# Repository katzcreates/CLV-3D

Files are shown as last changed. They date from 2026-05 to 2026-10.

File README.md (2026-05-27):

# CLV-3D: Closed Loop Ventilation Enclosure

A custom-built, sensor-driven ventilation enclosure designed for the safe operation of resin 3D printers in confined workshops.

## Overview

The CLV-3D is a multifunctional enclosure that addresses fume management and particulate filtration without requiring external exhaust. It features a high-volume recirculating airflow loop, real-time air quality monitoring, and autonomous fan control.

### Key Features

- **Recirculating Airflow**: Multi-pass filtration using G4 pre-filters and high-capacity carbon filters.
- **Distributed Sensor Network**: 4-node ESP-NOW system monitoring Internal, External, Plenum, and Filter environments.
- **Autonomous Control**: Fan speed scales automatically based on VOC (IAQ) and Particulate Matter (PM2.5 and PM10) levels.
- **Smart Idle & Self-Healing**: Adaptive power management and unified baseline calibration to prevent sensor drift.
- **Integrated Display**: Real-time dashboard showing system health and telemetry.

---

## Documentation

For detailed information on how to build, program, and maintain the CLV-3D, please refer to the following chapters:

- **[Electronics & Control Logic](docs/electronics.md)**: System architecture, wiring, and autonomous fan logic.
- **[Cabinetry & Assembly](docs/assembly.md)**: IKEA parts list, panel ordering, and physical construction.
- **[Firmware Setup & Calibration](docs/firmware.md)**: Library requirements, MAC addresses, and sensor calibration.
- **[Maintenance & Reliability](docs/maintenance.md)**: Filter lifespan, power management, and long-term stability.

*Documentation for Wireless Firmware coming soon.*

---

## System Architecture

The system consists of four wireless nodes communicating via ESP-NOW:

1. **Node 1 (Hub)**: Main display and user interface.
2. **Node 2 (Sensor Stack)**: Main control logic, fan driver, and internal sensors.
3. **Node 3 (Filter Monitor)**: Monitors pressure after the G4 filters to detect clogging.
4. **Node 4 (External Monitor)**: Reference node for room-air quality.

The as built system also features the following ventilation hardware:

- **Fan**: [Rhino Ultra Fan (150mm / 6" Non-Silenced)](https://rhinofilter.com/products/rhino-ultra-non-silenced-fan/)
- **Filter**: [AC Infinity 6" Carbon Filter](https://acinfinity.com/duct-carbon-filter-6-with-australian-charcoal/) (Intake)
- **Pre-filtration**: 2x [G4 Pleated Panel Filter (24"x12"x1" / EU4)](https://filtersdirect.uk/product/g4-pleated-panel-filter-1-22mm-depth-eu4/)

Other fans and filters can be used but adaptations to the design might be necessary to accomodate them. 

---

## Project Structure

- `firmware/`: Production firmware for all four nodes.
- `docs/`: Detailed technical documentation and assembly guides.
- `PressureCalibration/`: Utility script for sensor and pressure calibration.
- `3D Model References/`: Contains the master STEP assembly model (`CLV-3D Enclosure.step`) for the full enclosure.
- `3D Printing Files/`: Scaled STL files for all custom housings.
- `Cut Enclosure Pieces/`: DXF files for laser-cut panels.

---

## License & Credits

Designed by Katz Creates. This project is licensed under the **Creative Commons Attribution-NonCommercial-ShareAlike 4.0 International (CC BY-NC-SA 4.0)**.

See the [LICENSE](LICENSE) file for the full legal text.

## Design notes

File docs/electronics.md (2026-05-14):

# Electronics Design & Control Logic

The CLV-3D system follows a distributed design using ESP-NOW for wireless communication between a main display hub, a centralized sensor stack, and dedicated environmental monitors.

## System Architecture

```mermaid
graph TD
    subgraph "Node 1 - Hub (UM Feather S2)"
        N1[Feather S2] --- T["2.4 inch TFT FeatherWing"]
    end

    subgraph "Node 2 - Main Sensor Stack (QTPY S3)"
        N2[QTPY S3] --- S1[BME680 - Internal]
        N2[QTPY S3] --- S2[BME680 - Plenum]
        N2 --- PM[PMSA0031 - PM Sensor]
        N2 --- D[DAC 2 Unit - GP8413]
        D --- F[Rhino Ultra 150 EC Fan]
    end

    subgraph "Node 3 - Filter Monitor (QTPY S3)"
        N3[QTPY S3] --- S3[BME680 - Filter]
    end

    subgraph "Node 4 - External Monitor (QTPY S3)"
        N4[QTPY S3] --- S4[BME680 - External]
        N4 --- PM2[PMSA0031 - External PM Sensor]
    end

    N1 <--> |ESP-NOW| N2
    N1 <--> |ESP-NOW| N3
    N1 <--> |ESP-NOW| N4
```

## Node Pinouts

### Node 1: Main Hub (Feather S2)

| Pin | Component | Interface | Note |
| :--- | :--- | :--- | :--- |
| 1 | TFT_CS (LCD) | SPI | Chip Select for Display |
| 3 | TFT_DC (LCD) | SPI | Data/Command for Display |
| 33 | SD_CS (SD Card) | SPI | Chip Select for SD |
| 38 | STMPE_CS (Touch) | SPI | Chip Select for Resistive Touch |
| SCK/MO/MI | TFT/Touch/SD | SPI | Shared SPI |
| D5 | TFT Backlight | PWM | |

### Node 2: Main Sensor Stack (QTPY S3)

| Pin | Component | Interface | Note |
| :--- | :--- | :--- | :--- |
| SDA/SCL | BME680 (Internal) | I2C | STEMMA QT |
| SDA/SCL | BME680 (Plenum) | I2C | STEMMA QT |
| SDA/SCL | PMSA0031 (PM) | I2C | STEMMA QT |
| SDA/SCL | DAC 2 Unit (GP8413) | I2C (0x59) | V0 (Channel 0) for 0-10V Fan Control |

### Node 3: Filter Monitor (QTPY S3)

| Pin | Component | Interface | Note |
| :--- | :--- | :--- | :--- |
| SDA/SCL | BME680 (Filter) | I2C | STEMMA QT |

### Node 4: External Monitor (QTPY S3)

| Pin | Component | Interface | Note |
| :--- | :--- | :--- | :--- |
| SDA/SCL | BME680 (External) | I2C | STEMMA QT |
| SDA/SCL | PMSA0031 (PM External) | I2C | STEMMA QT |

### Hardware Configuration Notes

- **Communication**: ESP-NOW eliminates the need for data cables between nodes. Each node acts as a wireless station.
- **Fan Control**: The GP8413 provides a 0-10V analog signal from **Channel 0 (V0)** to the Rhino Ultra 150 EC fan.
- **Initialization**: Firmware initializes the DAC to a 10V range by writing `0x11` to register `0x01` on startup.

---

## Control Logic

The system operates autonomously, adjusting fan speed based on air quality and monitoring filter health via differential pressure.

### 1. VOC-Adaptive Fan Control (Hybrid Gradient)

- **Input**: BME680 (Internal) VOC IAQ Index (0-500 scale).
- **Output**: 0-10V DAC Signal to Rhino Ultra 150 EC.
- **Baseline**: 20% speed (~120 m³/h) for constant circulation when IAQ < 50.
- **Gradient**: Proportional ramp from 20% to 80% as IAQ index rises from 50 to 200.
- **Peak**: 100% speed if IAQ index exceeds 300 or Particulate Matter (PM2.5) exceeds 50 µg/m³.
- **Smoothing**: Exponential Moving Average (EMA) with a 0.2 smoothing factor to prevent rapid speed changes.

### 2. Adaptive "Smart Idle" Mode

- **Condition**: If `Internal IAQ < 30` for > 30 minutes, the fan drops to **0% speed**.
- **Adaptive Sniffing**:
  - **Standard**: 2 mins at 20% every 6 hours (if idle < 24h).
  - **Deep Sleep**: 2 mins at 20% every 24 hours (if idle > 24h).
- **Instant Wake**: Fan resumes normal operation if `IAQ > 55` or `PM2.5 > 15`.

### 3. G4 Filter Monitoring (Differential Pressure)

- **Method**: Comparison between Node 2 (Plenum) and Node 3 (Filter) BME680 pressure readings.
- **Threshold**: Final Pressure Drop = 250 Pa (normalized for current fan speed).
- **Alert**: "Replace G4 Filter" warning displayed on Node 1 when the normalized delta exceeds 250 Pa.

### 4. Carbon Filter Efficiency Monitoring

- **Method**: Comparison of VOC levels before and after the carbon bed (Internal vs. Plenum).
- **Calculation**: `Efficiency = (VOC_in - VOC_out) / VOC_in`.
- **Threshold**: Warning triggered if removal efficiency drops below 50% during a VOC event where Internal IAQ > 100.0 (Threshold increased to prevent ghost alerts during baseline healing).

### 5. Unified Self-Healing VOC System

To prevent the "Normalization Trap"—where sensors in clean, filtered air drift apart and memorize "extra-clean" as the new zero—the system uses an aggressive, multi-node synchronization strategy.

- **The Anchor (Node 4)**: As the external reference sitting in open workshop air, Node 4 is the ultimate authority on "True Zero." It nudges its own baseline by **10%** every 5 minutes of stability to ensure it finds 0 IAQ gradually and accurately.
- **Unified Shadow Nudging (Node 2)**:
  - **Sync Rate**: Every 5 minutes, if the Internal IAQ is stable (±3 points) but remains higher than the Room (Node 4), the system performs a **10% gentle nudge**.
  - **Shadowing**: To maintain accurate filter efficiency math, any nudge applied to the Internal baseline is automatically applied to the Plenum baseline in lock-step. This ensures they "heal" together and don't trigger false carbon alerts.
- **Safety Safeguards**:
  - **Stability Window**: A strict **±3-5 IAQ** jitter tolerance prevents standard sensor noise or fan speed changes from triggering a mathematical "healing" event prematurely.
  - **Print Guard (150 IAQ Ceiling)**: Downward nudging is automatically locked out if IAQ exceeds 150.0. This ensures the system never "zeros out" actual resin fumes during a print.
  - **Room Reference Gate**: Node 2 will only nudge downward if it has proof (from Node 4) that the room air is cleaner than the cabinet.
- **Persistence (5-Minute Checkpoints)**: The system checkpoints its calibration progress to the ESP32 Non-Volatile Storage (NVS) every **5 minutes**. This ensures that even during a "Rapid Climb" (first power-up), the board never loses more than 5 minutes of progress after a power cycle.

---

## Hub User Interface

The Hub (Node 1) provides the primary interface for monitoring system health and air quality.

- **Display**: 320x240 Landscape mode with dual-page touch navigation (Dashboard vs. System Status).
- **Diagnostics**: Real-time Node RSSI (dBm) and heartbeat indicators for all wireless sensors.
- **Alerting**: High-visibility headers for critical maintenance (`REPLACE G4` in Red, `REPLACE CARBON` in Orange).
- **Power Management**: Backlight automatically dims after 5 minutes of inactivity and turns off after 15 minutes. Wake-on-touch is supported.

---

*This project is licensed under [CC BY-NC-SA 4.0](https://creativecommons.org/licenses/by-nc-sa/4.0/).*

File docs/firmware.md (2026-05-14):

# Firmware Setup & Calibration

This guide covers the technical setup for the MCUs and the critical calibration steps required for accurate operation.

## 1. Requirements & Libraries

Ensure the following libraries are installed in the Arduino IDE:

- **Adafruit_BME680**: For Temp/Hum/Pressure/VOC sensors.
- **Adafruit_PM25AQI**: For the PMSA0031 particulate sensor.
- **Adafruit_ILI9341**: For the 2.4" TFT display.
- **Adafruit_GFX**: Core graphics library.
- **Adafruit_STMPE610**: For the resistive touch screen.

---

## 2. Identify MAC Addresses

To enable ESP-NOW communication, you need the MAC addresses of your boards. While your specific hardware will differ, here are the addresses used in the original build for reference:

- **Node 1 (Hub)**: `XX:XX:XX:XX:XX:XX`
- **Node 2 (Sensor Stack)**: `XX:XX:XX:XX:XX:XX`

### Setup Steps

1. Upload a "Get MAC" sketch to your boards to find their unique addresses.
2. Update the `hubAddress` in Node 2 and Node 4 to match your Node 1.
3. Update `node2Address` in Node 3 to match your Node 2.

---

## 3. Pressure & Filter Calibration

To ensure accurate mechanical clogging alerts for the G4 pre-filter, a baseline pressure calibration must be performed using the script in `PressureCalibration/` to account for sensor drift.

### Calibration Setup

- **Node 3 (Filter Monitor)**: Running its standard firmware.
- **Node 2 (Sensor Stack)**: Flashed with `PressureCalibration.ino`.

### Calibration Process

1. Open the Serial Monitor for Node 2 (115200 baud).
2. The script will cycle the fan from 0% to 100%.
3. **Capture the Tare**: Look at the `RawDiff` value when the Fan is at **0%**. This is the natural atmospheric difference between your specific sensors.
4. **Capture the Clean Baseline**: Look at the `FinalDrop` value when the Fan is at **80%**. For clean G4 filters, this is typically **3.0 to 5.0 Pa**.

### Updating Node 2 Firmware

1. Open `Node2_SensorStack.ino`.
2. Update `G4_FILTER_TARE_OFFSET` with your 0% `RawDiff` value (e.g., `-40.0`).
3. Ensure `G4_ALERT_THRESHOLD` is set to `5.0`. This triggers the alert only when resistance increases significantly above the clean baseline.
4. Note: The system uses a **30-second safe window** to prevent false alerts from door openings.

---

## 4. VOC & IAQ Calibration (Self-Healing)

The BME680 sensors automatically handle their own calibration via the **Unified Self-Healing** logic.

- **First-Run Sync**: On initial power-up, the system may report high IAQ (80-90) or stay at 0 while the raw resistance "climbs" to match your room air.
- **The Wait**: Simply leave the cabinet idle in a clean room for **15-20 minutes**. You will see the `Base` resistance climb in the Serial Monitor. Once the `Base` matches your room's raw resistance, local IAQ calibration is complete.
- **Autosave**: Progress is saved to flash every **5 minutes**.

---

## 5. Final Firmware Upload

Once calibration is complete, flash each node with its respective `.ino` file from the `firmware/` directory. Ensure Node 2 is flashed with its production firmware, NOT the calibration utility.

---

*This project is licensed under [CC BY-NC-SA 4.0](https://creativecommons.org/licenses/by-nc-sa/4.0/).*

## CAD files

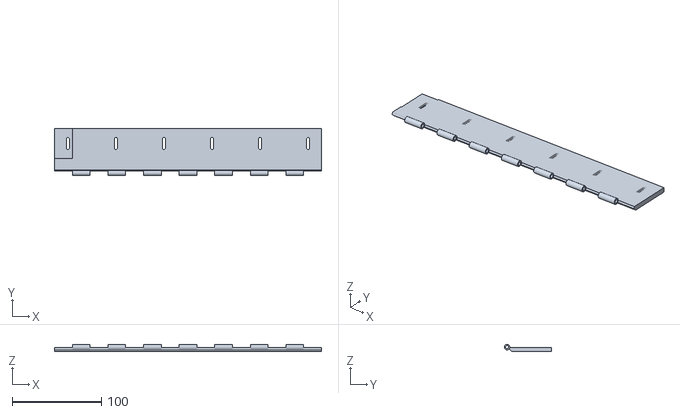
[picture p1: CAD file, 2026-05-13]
3D Printing Files/DoorTop_UpperHinge_Center_Right.stl
300.0 x 53.3 x 8.22

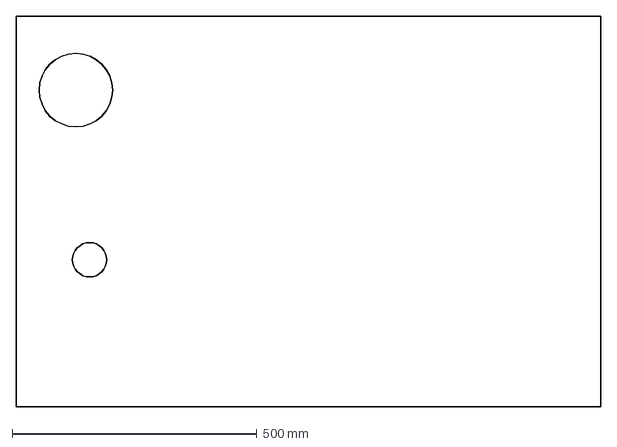
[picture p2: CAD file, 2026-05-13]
Cut Enclosure Pieces/Backsplash_FinalFix.dxf
1194.0 x 797.0 mm

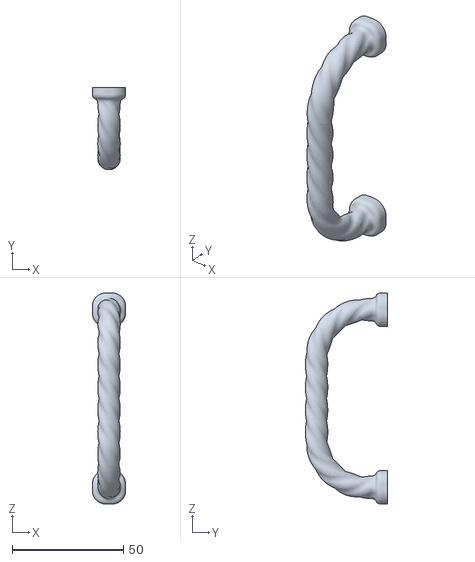
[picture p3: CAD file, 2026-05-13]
3D Printing Files/ClearHandle02.stl
15.0 x 37.1 x 95.0

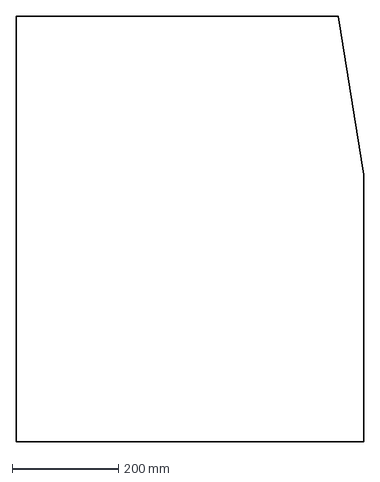
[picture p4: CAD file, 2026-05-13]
Cut Enclosure Pieces/AcrylicSideFix.dxf
653.0 x 800.0 mm

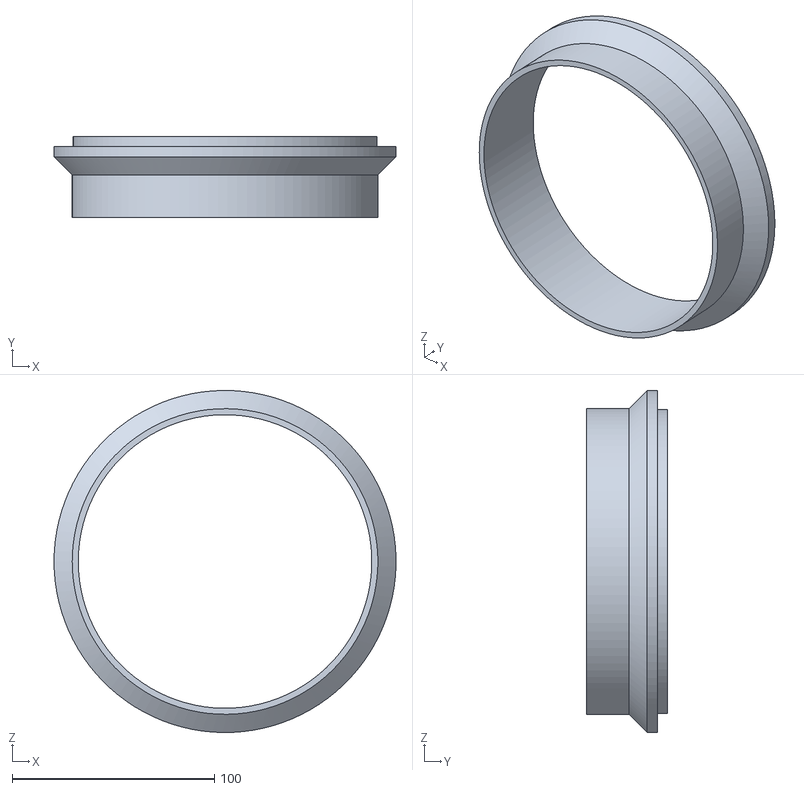
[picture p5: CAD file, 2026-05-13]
3D Printing Files/BacksplashFlange.stl
169.0 x 40.0 x 169.0

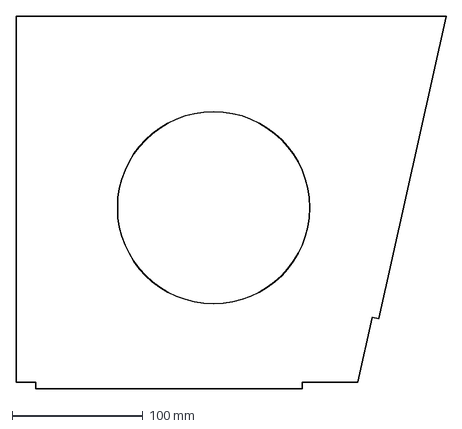
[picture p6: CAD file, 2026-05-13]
Cut Enclosure Pieces/FilterBlockerFix.dxf
328.9 x 285.1 mm

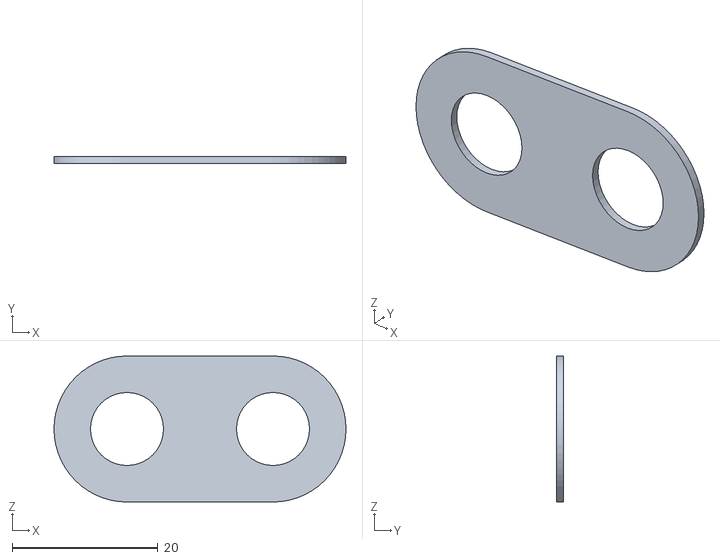
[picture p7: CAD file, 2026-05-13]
3D Printing Files/UpperCabinetMagnets.stl
40.0 x 1.00 x 20.0

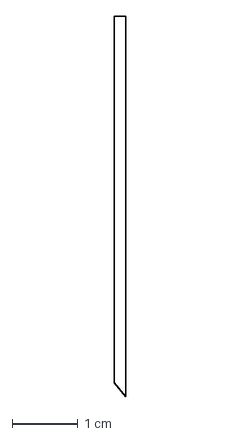
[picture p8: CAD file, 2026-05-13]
Cut Enclosure Pieces/AcrylicLowSide.dxf
0.18 x 5.77 cm

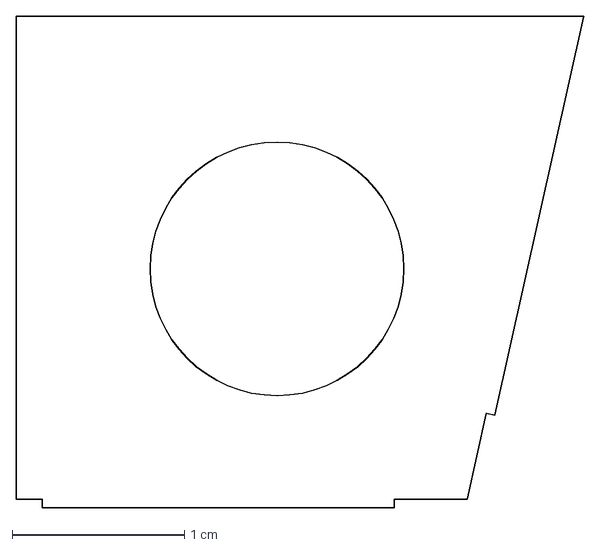
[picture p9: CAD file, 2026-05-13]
Cut Enclosure Pieces/FilterBlocker.dxf
3.29 x 2.85 cm

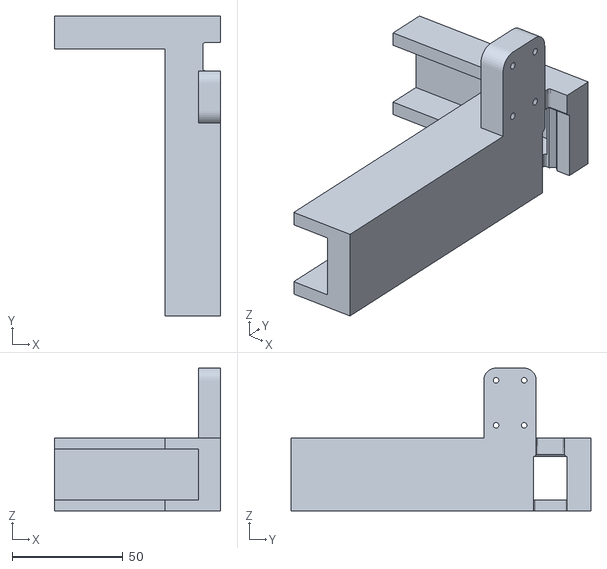
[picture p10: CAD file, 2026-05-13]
3D Printing Files/SideBackBracket.stl
75.0 x 135.5 x 64.5

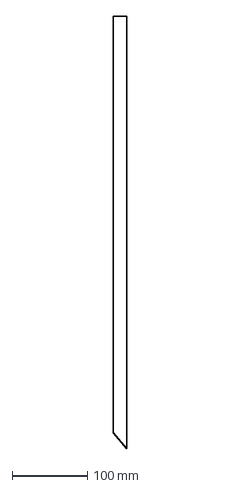
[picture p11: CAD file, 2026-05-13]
Cut Enclosure Pieces/AcrylicLowSideFix.dxf
18.0 x 576.7 mm

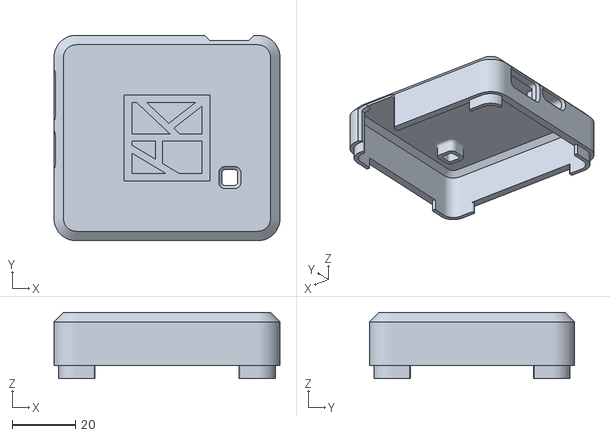
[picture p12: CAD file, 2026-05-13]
3D Printing Files/ExternalSensorLid.stl
71.6 x 65.1 x 21.0

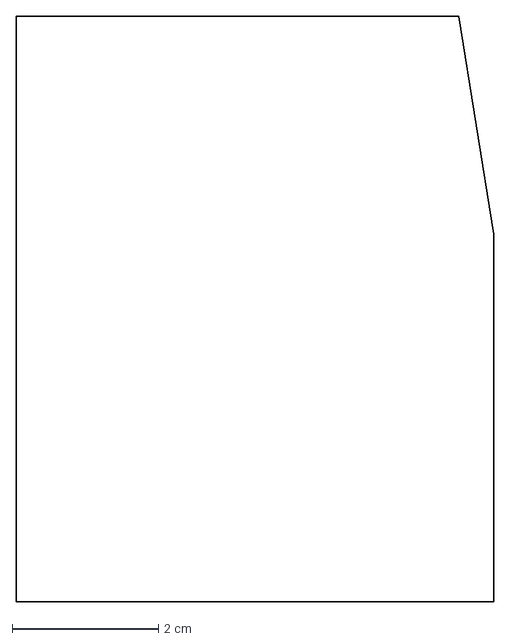
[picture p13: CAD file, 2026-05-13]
Cut Enclosure Pieces/AcrylicSide.dxf
6.53 x 8.00 cm

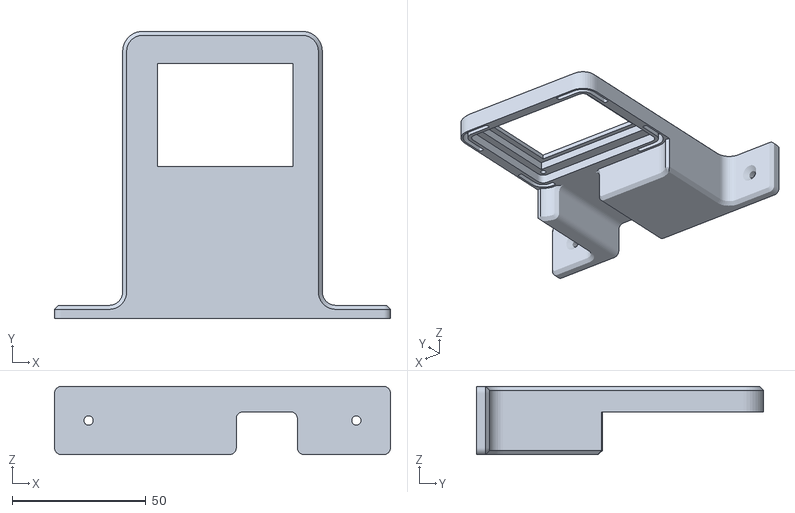
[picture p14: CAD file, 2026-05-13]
3D Printing Files/DisplayMountFront.stl
125.8 x 107.6 x 25.5

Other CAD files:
3D Printing Files/DoorTop_UpperHinge_Center_Left.stl
Cut Enclosure Pieces/Backsplash_Final.dxf
3D Printing Files/SideFrontLowerBracket.stl
Cut Enclosure Pieces/AcrylicBacksplash.dxf
3D Printing Files/BackBracket.stl
3D Printing Files/BackLid.stl
3D Printing Files/BracketSensorCover.stl
3D Printing Files/ClearHandle01.stl
3D Printing Files/DisplayBackCover.stl
3D Printing Files/DoorStop.stl
3D Printing Files/DoorStop_Large.stl
3D Printing Files/DoorStop_Medium.stl
3D Printing Files/DoorTop_Hinge_Edge_Right.stl
3D Printing Files/DoorTop_UpperHinge_Edge_Left.stl
3D Printing Files/DoorTop_UpperHinge_Edge_Right.stl
3D Printing Files/ExternalSensorBody.stl
3D Printing Files/Fan Spacer.stl
3D Printing Files/FilterSeparatorBracket.stl
3D Printing Files/FrontRemoveableBracket.stl
3D Printing Files/Grating_Hole.stl
3D Printing Files/Grating_Solid.stl
3D Printing Files/Handle01.stl
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

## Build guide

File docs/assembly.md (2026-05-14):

# Cabinetry & Enclosure Assembly

The CLV-3D is designed around the IKEA METOD modular kitchen system, providing a sturdy and professional-looking foundation for the enclosure.

## IKEA Parts List

### Lower Section (Storage & Base)

- 2x [METOD Base cabinet frame (60x60x80 cm)](https://www.ikea.com/gb/en/p/metod-base-cabinet-frame-black-grey-60591702/)
- 2x [VALLSTENA Door (60x80 cm, White)](https://www.ikea.com/gb/en/p/vallstena-door-white-80541693/)
- [FÖRBÄTTRA Plinth (Dark grey)](https://www.ikea.com/gb/en/p/foerbaettra-plinth-dark-grey-80454110/)
- [UTRUSTA Shelf (Black-grey)](https://www.ikea.com/gb/en/p/utrusta-shelf-black-grey-10591785/)
- [HÅLLBAR Bin with lid (Light grey)](https://www.ikea.com/gb/en/p/hallbar-bin-with-lid-light-grey-20420203/)
- [UTRUSTA Hinge w b-in damper (110°)](https://www.ikea.com/gb/en/p/utrusta-hinge-w-b-in-damper-for-kitchen-80524882/)
- [UTRUSTA Hinge w b-in damper (153°)](https://www.ikea.com/gb/en/p/utrusta-hinge-w-b-in-damper-for-kitchen-10427262/)
- 4x [METOD Leg](https://www.ikea.com/gb/en/p/metod-leg-70556067/)

### Upper Section (Filtration & Housing)

- 2x [METOD Fridge/freezer top cabinet frame (60x60x40 cm)](https://www.ikea.com/gb/en/p/metod-fridge-freezer-top-cabinet-frame-black-grey-70591706/)
- [MÖCKLERYD Worktop (White laminate)](https://www.ikea.com/gb/en/p/moeckleryd-worktop-white-laminate-60582180/)

### Drawers & Storage

- [KNIVSHULT Drawer low (Dark grey)](https://www.ikea.com/gb/en/p/knivshult-drawer-low-dark-grey-80600668/) (For Form 4, rated for weight)
- [KNIVSHULT Drawer medium (Dark grey)](https://www.ikea.com/gb/en/p/knivshult-drawer-medium-dark-grey-30600675/) (For consumables)
- [KNIVSHULT Drawer front low (Dark grey)](https://www.ikea.com/gb/en/p/knivshult-drawer-front-low-dark-grey-50600702/)
- [KNIVSHULT Drawer front medium (Dark grey)](https://www.ikea.com/gb/en/p/knivshult-drawer-front-medium-dark-grey-80600705/)

---

## Custom Panel Ordering

If you are using the same IKEA base furniture, you can refer to the `Cut Enclosure Pieces/` folder for DXF files for the exact pieces of acrylic and MDF that require custom shapes. For those in the UK, I recommend [CutMy.co.uk](https://cutmy.co.uk/).

### 3mm Clear Acrylic

| Dimensions (mm) | Qty | Shape | Note |
| :--- | :--- | :--- | :--- |
| 1200 x 297 | 1 | Rectangle | Top Door |
| 664 x 793 | 2 | Custom (Upload) | Side Panels (`AcrylicSide_FinalFix.dxf`) |
| 600 x 495 | 2 | Rectangle | Side Doors |

### 3mm Medite Premier MDF

| Dimensions (mm) | Qty | Shape | Note |
| :--- | :--- | :--- | :--- |
| 1194 x 797 | 1 | Custom (Upload) | Backsplash (`Backsplash_FinalFix.dxf`) |
| 329 x 285 | 1 | Custom (Upload) | Filter Baffle (`FilterBlockerFix.dxf`) |

---

## Enclosure Assembly Steps

1. **Upper/Wall Cabinets**: Install wall cabinets and secure to wall.
2. **Base Cabinets**: Assemble METOD base cabinets and test placement.
3. **Internal Prep**: Cut airflow holes in the back of the lower cabinet and countertop.
4. **Plenum Construction**: Create the rear plenum using foam/MDF.
5. **Base Placement:** Verify leg height is level and place base cabinet so plenum edges are flush against the wall.
6. **Drawers, Countertop & Hardware**: Install drawers and countertop and verify printer clearance.
7. **Backsplash:** Add in backsplash and secure to cabinets/countertop. Seal any major gaps or holes.
8. **Ventilation Install**: Mount inline fan and carbon filter to the bottom of the upper cabinets.
9. **Panels and Filters**: Install acrylic side panels, secure with L-brackets, and mount MDF baffle.
10. **Doors and Hinges:** Align hinges and mount the top and side doors.
11. **Electronics**: Integrate the ESP32-S3 nodes and sensor suite.

> [!TIP]
> **Gravity & Alignment**
> Real-world assembly often differs from CAD models due to mounting tolerances and "cabinet sag." It is highly recommended to complete the physical frame assembly and measure the specific "as-built" openings before cutting your final acrylic panels.

---

*This project is licensed under [CC BY-NC-SA 4.0](https://creativecommons.org/licenses/by-nc-sa/4.0/).*

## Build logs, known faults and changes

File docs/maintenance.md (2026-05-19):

# Maintenance & Reliability

The CLV-3D is designed for long-term industrial reliability. This guide covers sensor longevity, filter maintenance, and system stability.

## Component Lifespan Expectations

| Component | Life Expectancy | Maintenance Type |
| :--- | :--- | :--- |
| **BME680 (VOC)** | 5 - 10 Years | Self-calibrating via firmware nudges. |
| **PMSA0031 (PM)** | ~1.5 Years (24/7) | Can be extended to 10 years with SET-pin duty cycling. |
| **G4 Pre-Filter** | 3 - 6 Months | Replace when Hub reports `!! REPLACE G4 !!`. |
| **Carbon Filter** | ~18-24 Mo (Flip) | Replace after ~3 years total or when alerts persist. |
| **Rhino Fan** | 40,000+ Hours | Brushless EC motor, zero maintenance. |

## Smart Power Management (PM Sensor)

To prevent laser burnout, the system uses three power tiers for the PMSA0031 sensor:

1. **Active Mode (Continuous)**: Laser is 100% ON during prints, sanding, or painting for sub-second response.
2. **Idle Mode (Duty-Cycle)**: If the room is clean for 30 minutes, the laser sleeps and wakes every 10 minutes for a 30-second "sniff."
3. **Deep Sleep (OFF)**: If the shop is empty for >24 hours, the laser stays 100% OFF. It wakes instantly if the low-power VOC sensors detect any fumes (>100 IAQ) or if you touch the Hub.

> [!NOTE]
> **PMSA0031 Hardware Upgrade**
> The I2C version of the PM sensor requires a physical connection to its **SET pin** to enable software sleep. Currently, the laser is on 24/7 (1.5 year life). To enable the 10-year tiers, connect the sensor's SET pin to any spare GPIO on your QTPY and add a simple `digitalWrite` to the `pmIsSleeping` logic.

## Carbon Filter Maintenance

The cabinet contains two continuous VOC sources (Form Wash IPA and Form 4 resin vat). The fan's Smart Idle logic cycles it on and off as needed to maintain air quality without excessive filter wear.

| Milestone | Estimated Timeline | What to Do |
| :--- | :--- | :--- |
| **First Flip** | ~18–24 months | Rotate the filter 180° to bring the fresh end forward. |
| **Full Replacement** | ~3 years total | Replace the filter entirely. |

**How your firmware tells you it's time:**

- The Hub's **Carbon Alert** (`!! REPLACE CARBON !!`) fires when the Plenum VOC reading is within 50% of the Internal reading—i.e., air is passing through the carbon *without being scrubbed*.
- **Occasional alerts** → time to flip.
- **Persistent alerts** → time to replace.

> [!TIP]
> You don't need to track dates manually. Trust the Plenum sensor—it is measuring filter performance in real-time.

## Stability Hardening Flags

The firmware includes several "mathematical safety shields" to ensure decade-long operation without crashes or memory degradation:

- **Zero-Division Shield**: Protection against crashes if IAQ reach theoretical 0.0.
- **Baseline Sanity Caps**: VOC baselines are clamped between 10kΩ and 1,500kΩ to prevent digital "runaway."
- **Smart-Save Flash Protection**: The ESP32 only commits calibration data to flash if a change > 1% occurs, protecting the memory chips from wear-out over time.

---

*This project is licensed under [CC BY-NC-SA 4.0](https://creativecommons.org/licenses/by-nc-sa/4.0/).*

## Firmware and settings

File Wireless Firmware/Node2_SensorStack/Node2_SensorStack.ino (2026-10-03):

#include <WiFi.h>
#include <esp_now.h>
#include <ArduinoOTA.h>
#include <Wire.h>
#include <Adafruit_Sensor.h>
#include <Adafruit_BME680.h>
#include <Adafruit_PM25AQI.h>
#include <Preferences.h>
#include "../common/Protocol.h"
#include "../common/WirelessConfig.h"

// Forward Declaration for Compiler
void saveBaselines();

// I2C Addresses
#define BME680_INTERNAL_ADDR 0x77
#define BME680_PLENUM_ADDR   0x76 
#define GP8413_ADDR         0x59  // M5Stack Unit DAC2 default

// Fan Control Constants
#define MIN_FAN_SPEED 10
#define MAX_FAN_SPEED 80
#define PEAK_FAN_SPEED 100
#define CARBON_ALERT_WINDOW_MS 300000 
#define FILTER_ALERT_WINDOW_MS 30000 

// Smart Idle & Adaptive Sniffing Constants
#define IDLE_STABILITY_MS      3600000   // 1 Hour (must stay clean for a full hour)
#define SHORT_SNIFF_INTERVAL   21600000  // 6 Hours
#define LONG_SNIFF_INTERVAL    86400000  // 24 Hours
#define ADAPTIVE_THRESHOLD_MS  86400000  
#define SNIFF_DURATION_MS      120000    
#define BASELINE_SAVE_INTERVAL 300000    // 5 Minutes (Checkpoint Timer)
#define IAQ_WAKE_THRESHOLD     50.0      // Wake up threshold
#define IAQ_IDLE_THRESHOLD     10.0      // Entry buffer (Must be below 10 to start 1h timer)
#define PM_WAKE_THRESHOLD      15.0
#define PM10_WAKE_THRESHOLD    30.0

// Sensor Objects
Adafruit_BME680 bmeInternal(&Wire1);
Adafruit_BME680 bmePlenum(&Wire1);
Adafruit_PM25AQI pm25;

// Temperature Compensation
#define TEMP_OFFSET -13.0 // Reduced from -15.0 based on fan cooling data

// Peer Data
// Peer Data (Directed to Hub)
uint8_t hubAddress[] = {0x84, 0xF7, 0x03, 0x73, 0xB3, 0x7E}; // Node 1 (Hub) MAC
SensorData currentData;

// Global state / Calibration (Independent Baselines)
float gasBaselineInternal = 50.0;     
float gasBaselinePlenum = 50.0;      
const float gasBaselineWeight = 0.05; 
float smoothedFanSpeed = 0.0; 
const float fanSmoothingFactor = 0.2; 
float lastFilterPressure = 101325.0; 
uint32_t carbonAlertStartTime = 0; 
uint32_t filterAlertStartTime = 0; 

// Manual Control State
bool isManualMode = false;
uint8_t manualTargetSpeed = 50;
uint32_t manualModeStartTime = 0;

// UI Smoothing (EMA)
float smoothedIAQInternal = 0;
float smoothedIAQPlenum = 0;
float smoothedPM25 = 0;
float smoothedPM10 = 0;
const float uiSmoothingFactor = 0.5; // 0.5 is a good balance for numbers

// Configuration Offsets
const float G4_FILTER_TARE_OFFSET = -40.0; 
const float G4_ALERT_THRESHOLD = 5.0;      

// Adaptive Idle State Tracking
uint32_t lastActivityTime = 0;
uint32_t lastSniffTime = 0;
bool isSniffing = false;
bool isSystemIdle = false; 
Preferences preferences;
uint32_t lastBaselineSaveTime = 0;
uint32_t vocStableStartTime = 0;
float lastVocSyncRef = 0;
float lastExternalVOC = 30.0; 
uint32_t lastDriftCheckTime = 0;
float lastDriftRef = 0;
const uint32_t DRIFT_WINDOW_MS = 900000; // 15 Minutes for a drift nudge
uint32_t lastLogTime = 0;
bool pmIsSleeping = false;
uint32_t lastPmSampleTime = 0;
const uint32_t PM_SAMPLE_INTERVAL = 600000; // 10 Minutes (Duty-Cycle)
const uint32_t PM_WAKE_WINDOW = 30000;      // 30s sampling window

void onDataRecv(const esp_now_recv_info *info, const uint8_t *incomingData, int len) {
    if (len == sizeof(SensorData)) {
        SensorData *receivedData = (SensorData *)incomingData;
        if (receivedData->senderNode == 3) {
            lastFilterPressure = receivedData->filterStaticP;
        } else if (receivedData->senderNode == 4) {
            lastExternalVOC = receivedData->externalVOC;
        }
    } else if (len == sizeof(ControlCommand)) {
        ControlCommand *cmd = (ControlCommand *)incomingData;
        if (cmd->senderNode == 1) { // Node 1 (Hub)
            if (cmd->commandType == 1) { // Manual Mode Override
                isManualMode = true;
                manualTargetSpeed = cmd->manualSpeed;
                manualModeStartTime = millis();
                isSystemIdle = false;        // Interrupt Idle immediately
                lastActivityTime = millis(); // Reset the Idle countdown
                Serial.printf("Hub Override: Manual %d%% — Idle timer reset.\n", manualTargetSpeed);
            } else if (cmd->commandType == 0) { // Auto Mode
                isManualMode = false;
                lastActivityTime = millis(); // Start fresh 1-hour countdown
                Serial.println("Hub Override: Auto Mode — Idle timer reset.");
            }
        }
    }
}

void setFanSpeed(uint8_t percent) {
    percent = constrain(percent, 0, 100);
    uint16_t dacValue = (uint32_t)percent * 32767 / 100;
    uint16_t transmissionValue = dacValue << 1;
    
    Wire1.beginTransmission(GP8413_ADDR);
    Wire1.write(0x02); // Channel 0
    Wire1.write(transmissionValue & 0xFF);
    Wire1.write((transmissionValue >> 8) & 0xFF);
    Wire1.endTransmission();
    
    currentData.fanSpeed = percent;
}

// RH Compensation using the Magnus Formula
float compensateHumidity(float t_raw, float rh_raw, float t_comp) {
    // SVP = 6.112 * exp((17.625 * T) / (243.04 + T))
    auto svp = [](float t) {
        return 6.112 * exp((17.625 * t) / (243.04 + t));
    };
    float rh_true = rh_raw * (svp(t_raw) / svp(t_comp));
    return constrain(rh_true, 0.0, 100.0);
}

void setup() {
    Serial.begin(115200);
    Wire1.begin(); 
    
    // Initialize Sensors
    if (!bmeInternal.begin(BME680_INTERNAL_ADDR)) Serial.println("Internal BME680 Fail");
    if (!bmePlenum.begin(BME680_PLENUM_ADDR))     Serial.println("Plenum BME680 Fail");
    if (!pm25.begin_I2C(&Wire1))                  Serial.println("PMSA0031 Fail");

    // BME680 Settings (FOR BOTH SENSORS)
    auto configBME = [](Adafruit_BME680 &bme) {
        bme.setTemperatureOversampling(BME680_OS_8X);
        bme.setHumidityOversampling(BME680_OS_2X);
        bme.setPressureOversampling(BME680_OS_4X);
        bme.setIIRFilterSize(BME680_FILTER_SIZE_3);
        bme.setGasHeater(320, 150); 
    };
    configBME(bmeInternal);
    configBME(bmePlenum);

    // --- Wireless OTA: Connect WiFi & Init ESP-NOW ---
    setupWirelessOTA("cabinet-sensorstack");

    // --- ESP-NOW Callbacks & Peers (registered AFTER wireless init) ---
    esp_now_register_recv_cb(onDataRecv);

    Wire1.beginTransmission(GP8413_ADDR);
    Wire1.write(0x01); Wire1.write(0x11); // 10V Mode
    Wire1.endTransmission();

    // Register Hub Peer
    esp_now_peer_info_t peerInfo = {};
    memcpy(peerInfo.peer_addr, hubAddress, 6);
    peerInfo.channel = 0; 
    peerInfo.encrypt = false;
    esp_now_add_peer(&peerInfo);

    // Initialize Adaptive Idle
    lastActivityTime = millis();
    lastSniffTime = millis();

    // Load Persistent Baselines (Hardened Load)
    preferences.begin("voc-baseline", true); // Read-only
    gasBaselineInternal = preferences.getFloat("baseInt", 50.0);
    gasBaselinePlenum = preferences.getFloat("basePlen", 50.0);
    preferences.end();
    
    // Sanity check
    if (gasBaselineInternal < 1.0) gasBaselineInternal = 50.0;
    if (gasBaselinePlenum < 1.0) gasBaselinePlenum = 50.0;
    
    lastBaselineSaveTime = millis();

    Serial.println("\n--- Sensor Stack Setup Complete (Wireless OTA). Loop Starting ---");
}

void loop() {
    // --- OTA: Check for incoming wireless updates ---
    ArduinoOTA.handle();

    bool okInternal = bmeInternal.performReading();
    bool okPlenum = bmePlenum.performReading();
    
    // --- Smart PM Power Management ---
    uint32_t idleTime = millis() - lastActivityTime;
    bool shouldBeActive = !isSystemIdle || isManualMode;
    
    if (shouldBeActive) {
        pmIsSleeping = false; // Sensor stays on physically (I2C limitation)
    } else if (idleTime < 86400000) { // < 24 Hours: Duty Cycle
        uint32_t timeSinceSample = millis() - lastPmSampleTime;
        if (timeSinceSample > PM_SAMPLE_INTERVAL) {
            pmIsSleeping = false; 
            if (timeSinceSample > (PM_SAMPLE_INTERVAL + PM_WAKE_WINDOW)) {
                lastPmSampleTime = millis();
            }
        } else {
            pmIsSleeping = true; 
        }
    } else { // > 24 Hours: Deep Sleep
        pmIsSleeping = true; 
    }

    PM25_AQI_Data pmData;
    bool pmReadOk = false;
    if (!pmIsSleeping) pmReadOk = pm25.read(&pmData);

    // --- Process Internal VOC ---
    float iaqInternal = 0;
    if (okInternal) {
        float rInt = bmeInternal.gas_resistance / 1000.0;
        iaqInternal = map(constrain(rInt, gasBaselineInternal*0.1, gasBaselineInternal), gasBaselineInternal, gasBaselineInternal*0.1, 0, 500);
        
        // If Internal sees cleaner air, update its baseline.
        smoothedIAQInternal = (iaqInternal * uiSmoothingFactor) + (smoothedIAQInternal * (1.0 - uiSmoothingFactor));
        
        // --- Self-Healing Baseline Logic ---
        // 1. Upward (Shared Peak-Seeking): If Internal sees cleaner air, we update both.
        // This prevents the Plenum from 'normalizing' filtered air as its only zero.
        if (rInt > gasBaselineInternal) {
            gasBaselineInternal = (rInt * gasBaselineWeight) + (gasBaselineInternal * (1.0-gasBaselineWeight));
            gasBaselineInternal = constrain(gasBaselineInternal, 10.0, 1500.0); // Reality Cap
            
            if (okPlenum) {
                float rPlen = bmePlenum.gas_resistance / 1000.0;
                // Nudge Plenum upward to stay 'tethered' to the Internal reality.
                if (rPlen > gasBaselinePlenum) {
                    gasBaselinePlenum = (rPlen * gasBaselineWeight) + (gasBaselinePlenum * (1.0-gasBaselineWeight));
                    gasBaselinePlenum = constrain(gasBaselinePlenum, 10.0, 1500.0);
                }
            }
        } 
        // 2. Downward (Drift Correction): If air is stable (>10 IAQ) for 15m.
        else if (smoothedIAQInternal > 10.0) {
            if (abs(smoothedIAQInternal - lastDriftRef) < 10.0) { // Stable (relaxed) for 15m
                if (millis() - lastDriftCheckTime > DRIFT_WINDOW_MS) {
                    // Nudge baseline 10% closer to current resistance
                    gasBaselineInternal = (gasBaselineInternal * 0.90) + (rInt * 0.10);
                    gasBaselineInternal = constrain(gasBaselineInternal, 10.0, 1500.0);
                    lastDriftCheckTime = millis();
                    saveBaselines(); // Immediate Save
                    Serial.println(">> VOC Drift Correction: Nudging Baseline Down.");
                }
            } else {
                lastDriftCheckTime = millis();
                lastDriftRef = smoothedIAQInternal;
            }
        }

        if (millis() - lastLogTime > 5000) {
            Serial.printf("Internal: %.1fkOhm [Base: %.1f] IAQ: %.0f (Smooth: %.0f)\n", rInt, gasBaselineInternal, iaqInternal, smoothedIAQInternal);
        }
    }

    // --- Process Plenum VOC ---
    float iaqPlenum = 0;
    if (okPlenum) {
        float rPlen = bmePlenum.gas_resistance / 1000.0;
        
        // Plenum can also update its own baseline independently if it sees cleaner air.
        if (rPlen > gasBaselinePlenum) gasBaselinePlenum = (rPlen * gasBaselineWeight) + (gasBaselinePlenum * (1.0-gasBaselineWeight));

        // Use individual baseline for IAQ calculation (fixes the scale gap)
        iaqPlenum = map(constrain(rPlen, gasBaselinePlenum*0.1, gasBaselinePlenum), gasBaselinePlenum, gasBaselinePlenum*0.1, 0, 500);
        
        // UI Smoothing
        smoothedIAQPlenum = (iaqPlenum * uiSmoothingFactor) + (smoothedIAQPlenum * (1.0 - uiSmoothingFactor));
        
        // CLAMP: Physics check. Air after the filter cannot be dirtier than air before it. 
        if (smoothedIAQPlenum > smoothedIAQInternal) {
            smoothedIAQPlenum = smoothedIAQInternal;
            
            if (smoothedIAQInternal < 50.0) {
                // If the Plenum 'thinks' it is dirtier than the main cabinet air, it must be drifted.
                if (smoothedIAQPlenum > (smoothedIAQInternal + 5.0)) {
                    float rPlen = bmePlenum.gas_resistance / 1000.0;
                    gasBaselinePlenum = (rPlen * 0.05) + (gasBaselinePlenum * 0.95);
                }
            }
        } 
        if (millis() - lastLogTime > 5000) {
            Serial.printf("Plenum  : %.1fkOhm [Base: %.1f] IAQ: %.0f (Smooth: %.0f)\n", rPlen, gasBaselinePlenum, iaqPlenum, smoothedIAQPlenum);
            lastLogTime = millis();
        }
    }

    // PM2.5 Smoothing (Only update if awake and read succeeded)
    if (pmReadOk) {
        smoothedPM25 = ((float)pmData.pm25_env * uiSmoothingFactor) + (smoothedPM25 * (1.0 - uiSmoothingFactor));
        smoothedPM10 = ((float)pmData.pm10_env * uiSmoothingFactor) + (smoothedPM10 * (1.0 - uiSmoothingFactor));
    }

    // --- External Reference Sync (The Anchor) ---
    // Every 5 minutes, if air is stable, sanity-check against Room Air (Node 4).
    if (abs(smoothedIAQInternal - lastVocSyncRef) < 10.0) {
        if (millis() - vocStableStartTime > 300000) { // 5 Minute Stability
            // Unified Self-Healing: The Plenum 'shadows' the Internal's drift correction.
            if (smoothedIAQInternal < 150.0) {
                float roomRef = lastExternalVOC + 5.0; // Room Ref + 5pt buffer
                
                if (smoothedIAQInternal > roomRef) {
                    // Pull BOTH baselines down by 10% (Gently) to maintain relative filter performance.
                    float rIntRaw = bmeInternal.gas_resistance / 1000.0;
                    gasBaselineInternal = (gasBaselineInternal * 0.90) + (rIntRaw * 0.10);
                    gasBaselineInternal = constrain(gasBaselineInternal, 10.0, 1500.0);
                    
                    float rPlenRaw = bmePlenum.gas_resistance / 1000.0;
                    gasBaselinePlenum = (gasBaselinePlenum * 0.90) + (rPlenRaw * 0.10);
                    gasBaselinePlenum = constrain(gasBaselinePlenum, 10.0, 1500.0);

                    Serial.printf(">> Unified System Sync: Room=%.1f\n", lastExternalVOC);
                    saveBaselines(); // Immediate Save
                }
                vocStableStartTime = millis(); 
            }
        }
    } else {
        vocStableStartTime = millis();
        lastVocSyncRef = smoothedIAQInternal;
    }

    // --- Adaptive Idle & Fan Logic ---
    uint8_t targetSpeed = 0;

    // 1. Detect WAKE triggers (Transitions Idle -> Active)
    if (smoothedIAQInternal > IAQ_WAKE_THRESHOLD || smoothedPM25 > PM_WAKE_THRESHOLD || smoothedPM10 > PM10_WAKE_THRESHOLD) {
        if (isSystemIdle) {
            Serial.println(">> IAQ/PM Threshold Trip: Waking Fan.");
            isSystemIdle = false;
        } else {
            // Only log the reset reason occasionally to avoid spam
            static uint32_t lastResetLog = 0;
            if (millis() - lastResetLog > 60000) {
                if (smoothedIAQInternal > IAQ_WAKE_THRESHOLD) Serial.printf(">> Activity Reset: High VOC (%.1f)\n", smoothedIAQInternal);
                else if (smoothedPM25 > PM_WAKE_THRESHOLD) Serial.printf(">> Activity Reset: High PM2.5 (%.1f)\n", smoothedPM25);
                else Serial.printf(">> Activity Reset: High PM10 (%.1f)\n", smoothedPM10);
                lastResetLog = millis();
            }
        }
        lastActivityTime = millis();
        isSniffing = false; 
    }

    // 2. Detect IDLE conditions (Transitions Active -> Idle)
    if (!isSystemIdle && !isManualMode) {
        // Must be clean across ALL metrics to proceed to idle
        if (smoothedIAQInternal > IAQ_IDLE_THRESHOLD || smoothedPM25 > 5.0 || smoothedPM10 > 10.0) {
            // Air is not clean enough to be idle; reset the timer
            lastActivityTime = millis();
        } else {
            // Air is clean; proceed towards idle (countdown is active)
            uint32_t elapsed = millis() - lastActivityTime;
            if (elapsed > IDLE_STABILITY_MS) {
                Serial.println(">> Air Stable for 30m: Entering Smart Idle.");
                isSystemIdle = true;
                lastSniffTime = millis();
            } else {
                // Periodically log the countdown progress for debugging
                static uint32_t lastProgressLog = 0;
                if (millis() - lastProgressLog > 300000) { // Every 5 mins
                    Serial.printf(">> Idle Countdown: %.0f min remaining...\n", (float)(IDLE_STABILITY_MS - elapsed)/60000.0);
                    lastProgressLog = millis();
                }
            }
        }
    }

    // 3. Handle Manual Mode Override
    if (isManualMode) {
        if (millis() - manualModeStartTime > 600000) { // 10 min auto-revert
            isManualMode = false;
            isSystemIdle = false;        // Never jump straight back to Idle
            lastActivityTime = millis(); // Must serve the full 1-hour countdown
            Serial.println("Manual mode expired. Starting fresh 1-hour Idle countdown.");
        } else {
            targetSpeed = manualTargetSpeed;
        }
    }

    // 4. Set Target Speed based on State
    if (!isManualMode) {
        if (!isSystemIdle) {
            // ACTIVE STATE: Calculate required speeds for each metric
            long vocSpeed = MIN_FAN_SPEED;
            long pm25Speed = MIN_FAN_SPEED;
            long pm10Speed = MIN_FAN_SPEED;

            if (smoothedIAQInternal > 50) vocSpeed = map((long)smoothedIAQInternal, 50, 200, MIN_FAN_SPEED, MAX_FAN_SPEED);
            if (smoothedIAQInternal > 300) vocSpeed = PEAK_FAN_SPEED;

            if (smoothedPM25 > PM_WAKE_THRESHOLD) pm25Speed = map((long)smoothedPM25, (long)PM_WAKE_THRESHOLD, 150, MIN_FAN_SPEED, PEAK_FAN_SPEED);
            if (smoothedPM10 > PM10_WAKE_THRESHOLD) pm10Speed = map((long)smoothedPM10, (long)PM10_WAKE_THRESHOLD, 300, MIN_FAN_SPEED, PEAK_FAN_SPEED);

            // Select the highest required speed
            long highestSpeed = max(vocSpeed, max(pm25Speed, pm10Speed));
            
            // Constrain just in case map() overshoots
            targetSpeed = (uint8_t)constrain(highestSpeed, MIN_FAN_SPEED, PEAK_FAN_SPEED);
        } else {
            // IDLE STATE: 0% speed (plus adaptive sniffing)
            uint32_t idleDuration = millis() - lastActivityTime;
            uint32_t sniffInterval = (idleDuration < ADAPTIVE_THRESHOLD_MS) ? SHORT_SNIFF_INTERVAL : LONG_SNIFF_INTERVAL;
            uint32_t timeSinceSniff = millis() - lastSniffTime;

            if (timeSinceSniff > sniffInterval) {
                targetSpeed = 20; 
                isSniffing = true;
                if (timeSinceSniff > (sniffInterval + SNIFF_DURATION_MS)) {
                    lastSniffTime = millis();
                    targetSpeed = 0;
                    isSniffing = false;
                }
            } else {
                targetSpeed = 0;
                isSniffing = false;
            }
        }
    }

    smoothedFanSpeed = (targetSpeed * fanSmoothingFactor) + (smoothedFanSpeed * (1.0 - fanSmoothingFactor));
    setFanSpeed((uint8_t)round(smoothedFanSpeed));

    // Periodic Baseline Save
    if (millis() - lastBaselineSaveTime > BASELINE_SAVE_INTERVAL) {
        saveBaselines();
        lastBaselineSaveTime = millis();
    }

    // G4 Filter Health (Pressure Differential with Software Tare)
    float pInt = bmeInternal.pressure;
    float pFil = lastFilterPressure;
    float g4Drop = (pInt - pFil) - G4_FILTER_TARE_OFFSET;

    if (okInternal) {
        // Only evaluate pressure drop if the fan is actually pulling significant air
        if (smoothedFanSpeed > 30.0 && g4Drop > G4_ALERT_THRESHOLD) {
            if (filterAlertStartTime == 0) filterAlertStartTime = millis();
            uint32_t elapsed = millis() - filterAlertStartTime;
            
            if (elapsed > FILTER_ALERT_WINDOW_MS) {
                currentData.filterAlert = true;
                Serial.printf("!! G4 FILTER ALERT ACTIVE (Drop: %.1f) !!\n", g4Drop);
            } else {
                Serial.printf("G4 PENDING: %.0fs (Drop: %.1f)\n", (float)(FILTER_ALERT_WINDOW_MS - elapsed)/1000.0, g4Drop);
            }
        } else {
            filterAlertStartTime = 0;
            currentData.filterAlert = false;
        }
    } else {
        // SENSOR GLITCH: We do NOT reset the timer here. We just skip this loop's update.
        // This makes the alert 'sticky' even if the I2C bus is noisy.
    }
    if (okPlenum) currentData.plenumStaticP = bmePlenum.pressure;

    // Carbon Filter Health (Efficiency check with time-based window)
    if (smoothedIAQInternal > 100.0) { 
        float efficiency = 0;
        if (smoothedIAQInternal > 0.1) { // Zero-Division Shield
            efficiency = (smoothedIAQInternal - smoothedIAQPlenum) / smoothedIAQInternal;
        }
        
        if (efficiency < 0.5) {
            if (carbonAlertStartTime == 0) carbonAlertStartTime = millis();
            if (millis() - carbonAlertStartTime > CARBON_ALERT_WINDOW_MS) {
                currentData.carbonAlert = true;
            }
        } else {
            carbonAlertStartTime = 0;
            currentData.carbonAlert = false;
        }
    } else {
        carbonAlertStartTime = 0;
        currentData.carbonAlert = false;
    }

    // Pack Telemetry
    if (okInternal) {
        float tRaw = bmeInternal.temperature;
        float tComp = tRaw + TEMP_OFFSET;
        currentData.internalTemp = tComp;
        currentData.internalHum = compensateHumidity(tRaw, bmeInternal.humidity, tComp);
        currentData.internalVOC = smoothedIAQInternal;
        currentData.internalStaticP = bmeInternal.pressure;
    }
    currentData.particulate = smoothedPM25;
    currentData.particulate10 = smoothedPM10;
    currentData.plenumVOC = smoothedIAQPlenum;
    currentData.senderNode = 2;
    currentData.fanSpeed = (uint8_t)round(smoothedFanSpeed); // FIX: Pack actual dynamic speed for the Hub's local sync
    // Send telemetry directly to Hub
    esp_now_send(hubAddress, (uint8_t *) &currentData, sizeof(currentData));
    delay(2000); 
}
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

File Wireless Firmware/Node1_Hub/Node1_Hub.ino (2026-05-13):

#include <WiFi.h>
#include <esp_now.h>
#include <ArduinoOTA.h>
#include <HTTPClient.h>
#include <Adafruit_GFX.h>
#include <Adafruit_ILI9341.h>
#include <Adafruit_STMPE610.h>
#include <Fonts/FreeSans9pt7b.h>
#include <Fonts/FreeSansBold9pt7b.h>
#include <Fonts/FreeSansBold18pt7b.h>
#include <Preferences.h>
#include "../common/Protocol.h"
#include "../common/WirelessConfig.h"

// TFT Pins for Feather S2 + 2.4" TFT Wing
#define STMPE_CS 38
#define TFT_CS   1
#define TFT_DC   3
#define AD_CS    33
#define TFT_LED  8

#define DIM_TIME   300000 
#define SLEEP_TIME 900000 

Adafruit_ILI9341 tft = Adafruit_ILI9341(TFT_CS, TFT_DC);
Adafruit_STMPE610 touch = Adafruit_STMPE610(STMPE_CS);

#define CLR_BG      0x0821
#define CLR_CARD    0x2104
#define CLR_TEXT    0xFFFF
#define CLR_HEADER  0x4A69
#define CLR_GOOD    0x5700
#define CLR_WARN    0xE620
#define CLR_BAD     0xD000
#define CLR_PURPLE  0x780F
#define CLR_ACCENT  0x039F

SensorData node2Data;
SensorData node4Data;
uint8_t currentPage = 0;
uint32_t lastSeenNode2 = 0, lastSeenNode3 = 0, lastSeenNode4 = 0;
int8_t rssiNode2 = 0, rssiNode3 = 0, rssiNode4 = 0;
uint32_t lastTouchTime = 0, lastPageSwitch = 0;
bool isSleeping = false, isDimmed = false;

// Manual Control variables
uint8_t node2Mac[6];
// UI State
uint32_t lastDisplayUpdate = 0;
const uint32_t displayInterval = 1000; // Refresh display every 1 second automatically

// Node State
bool isNode2Paired = false;
uint8_t currentManualSpeed = 80;
uint32_t lastManualPressTime = 0;

// Cloud Publishing
uint32_t lastCloudPush = 0;

void sendControlCommand(uint8_t type, uint8_t speed) {
    if (!isNode2Paired) return;
    ControlCommand cmd;
    cmd.commandType = type;
    cmd.manualSpeed = speed;
    cmd.senderNode = 1;
    esp_now_send(node2Mac, (uint8_t*)&cmd, sizeof(cmd));
}

uint16_t getIAQColor(float val) {
    if (val < 100) return CLR_GOOD;
    if (val < 250) return CLR_WARN;
    return CLR_BAD;
}

void onDataRecv(const esp_now_recv_info *info, const uint8_t *incomingData, int len) {
    Serial.printf("Received %d bytes from Node %d\n", len, ((SensorData*)incomingData)->senderNode);
    if (len == sizeof(SensorData)) {
        SensorData *newData = (SensorData *)incomingData;
        if (newData->senderNode == 2) {
            if (!esp_now_is_peer_exist(info->src_addr)) {
                memcpy(node2Mac, info->src_addr, 6);
                esp_now_peer_info_t peerInfo = {};
                memcpy(peerInfo.peer_addr, node2Mac, 6);
                peerInfo.channel = 0;
                peerInfo.encrypt = false;
                esp_now_add_peer(&peerInfo);
                isNode2Paired = true;
            }
            lastSeenNode2 = millis();
            rssiNode2 = info->rx_ctrl->rssi;
            node2Data = *newData;
        } else if (newData->senderNode == 3) {
            lastSeenNode3 = millis();
            rssiNode3 = info->rx_ctrl->rssi;
            node2Data.filterStaticP = newData->filterStaticP;
        } else if (newData->senderNode == 4) {
            lastSeenNode4 = millis();
            rssiNode4 = info->rx_ctrl->rssi;
            node4Data = *newData;
        }
        // updateDisplay() REMOVED from this interrupt/callback to prevent severe SPI bus collisions!
        // The display is now safely and smoothly updated by the 1-second background refresh in loop().
    }
}

void drawHeader() {
    uint16_t headerCol = CLR_HEADER;
    const char* alertMsg = "AIR QUALITY DASHBOARD";
    if (currentPage == 1) { headerCol = 0x3186; alertMsg = "SYSTEM STATUS"; }
    else if (currentPage == 2) { headerCol = 0x9300; alertMsg = "MANUAL FAN CONTROL"; }

    if (node2Data.filterAlert && node2Data.carbonAlert) { headerCol = CLR_BAD; alertMsg = "!! CLOGGED FILTERS !!"; }
    else if (node2Data.filterAlert) { headerCol = CLR_BAD; alertMsg = "!! REPLACE G4 FILTER !!"; }
    else if (node2Data.carbonAlert) { headerCol = CLR_WARN; alertMsg = "!! REPLACE CARBON FILTER !!"; }
    
    tft.fillRect(0, 0, 320, 35, headerCol);
    tft.setFont(&FreeSansBold9pt7b);
    tft.setTextColor(CLR_TEXT);
    tft.setCursor(10, 24); 
    tft.print(alertMsg);
}

void drawPage0Static() {
    tft.fillScreen(CLR_BG);
    drawHeader();
    
    tft.setFont(&FreeSans9pt7b);
    tft.setTextColor(0xAD55);
    tft.setCursor(30, 50); tft.print("CABINET (INT)");
    tft.setCursor(185, 50); tft.print("ROOM (EXT)");
    tft.drawRoundRect(5, 60, 150, 48, 6, CLR_CARD);
    tft.drawRoundRect(165, 60, 150, 48, 6, CLR_CARD);
    tft.drawRoundRect(5, 120, 310, 100, 6, CLR_CARD);
    tft.setFont(NULL);
    tft.setCursor(12, 64); tft.print("VOCs");
    tft.setCursor(172, 64); tft.print("VOCs");
    tft.setCursor(12, 127); tft.print("DETAILED COMPARISON");
    tft.setCursor(205, 225); tft.print("SYSTEM STATUS >");
}

void drawPage1Static() {
    tft.fillScreen(CLR_BG);
    drawHeader();
    
    tft.setFont(&FreeSans9pt7b);
    tft.setTextColor(0xAD55);
    tft.setCursor(10, 60); tft.print("NETWORK NODES");
    for(int i=0; i<3; i++) tft.drawRoundRect(5, 75 + (i*40), 310, 35, 4, CLR_CARD);
    tft.setFont(NULL);
    tft.setCursor(35, 87); tft.print("NODE 2 (Stack)");
    tft.setCursor(35, 127); tft.print("NODE 3 (Filter)");
    tft.setCursor(35, 167); tft.print("NODE 4 (Ambient)");
    tft.setCursor(195, 225); tft.print("MANUAL CONTROL >");
}

void drawPage2Static() {
    int16_t x1, y1; uint16_t w, h;
    tft.fillScreen(CLR_BG);
    drawHeader();
    
    tft.setFont(&FreeSans9pt7b);
    
    // Auto Button (Bottom Left: 5, 175, 150, 45)
    tft.fillRoundRect(5, 175, 150, 45, 6, CLR_GOOD);
    const char* txtAuto = "AUTO MODE";
    tft.getTextBounds(txtAuto, 0, 0, &x1, &y1, &w, &h);
    tft.setCursor(80 - (w/2), 197 - (y1 + h/2));
    tft.print(txtAuto);

    // Boost Button (Bottom Right: 165, 175, 150, 45)
    tft.fillRoundRect(165, 175, 150, 45, 6, CLR_BAD);
    const char* txtBoost = "BOOST MODE";
    tft.getTextBounds(txtBoost, 0, 0, &x1, &y1, &w, &h);
    tft.setCursor(240 - (w/2), 197 - (y1 + h/2));
    tft.print(txtBoost);
    
    // Down Button (Left middle)
    tft.fillRoundRect(5, 100, 50, 50, 6, CLR_CARD);
    tft.setCursor(20, 131); tft.print("-");
    
    // Up Button (Right middle)
    tft.fillRoundRect(265, 100, 50, 50, 6, CLR_CARD);
    tft.setCursor(282, 131); tft.print("+");

    tft.setTextColor(0xAD55);
    tft.setCursor(135, 60); tft.print("SPEED");
    tft.setFont(NULL);
    tft.setCursor(225, 225); tft.print("DASHBOARD >");
}

void updatePage2() {
    tft.fillRect(70, 75, 180, 80, CLR_BG); // Clear center area
    tft.setFont(&FreeSansBold18pt7b);
    tft.setTextColor(CLR_TEXT);
    char buf[16];
    int16_t x1, y1; uint16_t w, h;
    uint8_t displaySpeed = (millis() - lastManualPressTime < 3000) ? currentManualSpeed : node2Data.fanSpeed;
    sprintf(buf, "%d%%", displaySpeed);
    tft.getTextBounds(buf, 0, 0, &x1, &y1, &w, &h);
    tft.setCursor(160 - (w/2), 125); 
    tft.print(buf);
}
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

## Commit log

2026-05-13 Initial commit: Reorganized project structure and added professional README
    [AcrylicBacksplash.dxf, AcrylicFunnel.dxf, AcrylicLowSide.dxf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]
2026-05-13 README: Update carbon filter description to 'high-capacity carbon filters'
2026-05-13 Restore separate common folders for firmware and Wireless Firmware branches
2026-05-13 Fix formatting of Wireless Firmware Instructions header
2026-05-13 Enhance electronics documentation with control logic details
    Added detailed explanations for fan control logic and filter monitoring strategies, including adaptive modes and self-healing mechanisms.
2026-05-13 Docs: Restore missing IKEA hinges and drawers to assembly.md
2026-05-13 Docs: Correct hinge degree labels (110° and 153°)
2026-05-13 Docs: Restore detailed carbon filter alert logic to maintenance.md
2026-05-13 Add note for upcoming wireless firmware documentation
    Added note about upcoming wireless firmware documentation.
2026-05-14 Docs: Fix Markdown lint errors in assembly.md
2026-05-14 Cleanup: Remove redundant Calibration/ folder level and update docs
2026-05-14 Update description of 3D Printing Files in README
2026-05-19 CAD: Add master enclosure STEP model and update README
2026-05-27 Update README with ventilation hardware information
    Added details about ventilation hardware and filter options.
2026-09-30 Fix Smart Idle logic in Wireless Firmware
    [VaseBulbInsert.stl]
2026-09-30 Delete VaseBulbInsert.stl
    Accidental file upload.
    [VaseBulbInsert.stl]
2026-10-03 refactor(Node2): Tighten Smart Idle thresholds and fix Manual Mode interrupt
    - Raise idle entry requirement from IAQ < 35 to IAQ < 10; system must now
    see genuinely clean air before the countdown begins
    - Extend idle stability window from 30 minutes to 1 hour to prevent
    short-cycling when fumes dissipate quickly
    - Lower wake threshold from 55/100 IAQ to 50 IAQ for faster fan response
    at first sign of fumes
    - Fix Manual Mode entry: now immediately clears isSystemIdle and resets
    lastActivityTime so Idle is properly interrupted when Hub takes control
    - Fix Manual Mode expiry: 10-minute auto-revert now resets lastActivityTime
    rather than silently reverting, preventing the fan from jump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
    [Node2_SensorStack.ino]
2026-10-20 build(git): ignore WirelessConfig.h to protect credentials
2026-10-21 fix(firmware): two-tier carbon alert, safe drift logic, and high humidity banner
    - Add two-tier carbon monitoring: Level 1 Warning (<70% eff, 15m) and Level 2 Critical (<50% eff, 20m)
    - Implement purple header banner (CLR_PURPLE) on Hub when cabinet humidity >60%
    - Add true pause freeze for carbon alert timers during humidity spikes and external room events
    - Gate downward baseline drift strictly to <25 IAQ to prevent normalizing resin fumes
    - Replace forced room down-sync with Node 4 cooking/event shield
    - Fix dead code in plenum drift check and remove artificial idle clamping
    - Add carbon_eff to cloud InfluxDB payload in wireless Hub
2026-10-23 Update PM power logic across all nodes and introduce Wireless Firmware suite
2026-10-23 Fixed InfluxDB integer parsing issue for wireless data submission.
2026-10-24 Fixed OTA connection glitch, and updated G4 filter alerts to new time based system
2026-10-25 Increased time interval for Carbon Filter alerts
